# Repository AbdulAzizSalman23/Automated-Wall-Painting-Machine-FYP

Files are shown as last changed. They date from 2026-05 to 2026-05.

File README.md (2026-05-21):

# 🤖 Automated Wall Painting Machine
### Final Year Engineering Project | B.E. Mechanical Engineering
**Don Bosco College of Engineering, Goa University | 2022–23**  
**Team of 5 | Guide: Prof. Sachin Turi | Grade: O (Outstanding)**

---

## 📌 Problem Statement

| | Manual Painting | MYRO Commercial Robot | Our Machine |
|---|---|---|---|
| Cost | ₹3,000 labour/1,500 sq.ft | ₹15,00,000+ | **₹27,857** |
| Max height | Human reach (~2m) | 1.83m | **3.0m** |
| Portability | N/A | ❌ No | **✅ Yes** |
| Chemical exposure | High (VOCs) | Low | **Low** |

Manual wall painting exposes workers to toxic VOCs (benzene, toluene) and is limited by human reach. Commercial robots are unaffordable for typical use. This project builds a low-cost, portable, automated alternative.

---

## 🎥 System Overview

> *
*

The machine covers **3 metres height × 2 metres width** — standard Indian room dimensions. It operates autonomously once placed on the track, detecting and avoiding obstacles such as windows and switchboards.

---

## ⚙️ System Architecture
┌─────────────────────────────────────────┐
│              BASE ASSEMBLY              │
│  PMDC Motor (350W) + Arduino Uno        │
│  Geared Box Motor + 2m Lateral Track    │
└────────────────┬────────────────────────┘
│
┌────────────────▼────────────────────────┐
│         FRAME ASSEMBLY (x2)             │
│  Telescopic mild steel frames           │
│  Rope-pulley vertical drive             │
│  Reaches ~3m height                     │
└────────────────┬────────────────────────┘
│
┌────────────────▼────────────────────────┐
│       PAINT DISPENSING SYSTEM           │
│  HVLP Spray Gun + 3D-printed bracket   │
│  100N Linear Actuator (trigger)         │
│  HC-SR04 Ultrasonic Sensors (x2)        │
└─────────────────────────────────────────┘

---

## 🔄 Control Logic (Arduino State Machine)
STARTUP → Reset to zero position (home)
│
└── LOOP:
├── 1. Activate spray gun (linear actuator ON)
├── 2. Move paint system UPWARD (PMDC motor)
├── 3. Ultrasonic sensor check:
│       obstacle detected? → pause spray, continue movement
│       no obstacle?       → spray active
├── 4. Top limit switch triggered → deactivate spray
├── 5. Move DOWNWARD to home position
├── 6. Lateral shift: 75mm sideways (geared box motor)
└── 7. Repeat until full wall covered
---

## 🔧 Key Design Iterations

| Subsystem | Attempt 1 | Attempt 2 | Final Solution | Reason |
|---|---|---|---|---|
| Vertical drive | Lead-screw | — | **Rope-pulley** | Lighter, simpler, lower cost |
| Lateral movement | Mecanum wheels | — | **Track system** | More reliable, no slippage |
| Spray trigger | Servo motor | Solenoid valve | **100N Linear Actuator** | Only option with sufficient force |
| Obstacle detection | Multiple sensor types | — | **Single HC-SR04** | Simplified wiring, sufficient accuracy |

---

## 🛠️ Technical Specifications

| Parameter | Value |
|---|---|
| Vertical reach | ~3.0 metres |
| Lateral coverage | 2.0 metres (2m track) |
| Lateral strip width | 75mm per pass |
| Gun-to-wall distance | 190mm |
| Operating pressure | 100 PSI |
| Motor power (vertical) | 350W PMDC |
| Trigger actuator force | 100N |
| Obstacle detection | HC-SR04 ultrasonic (range: 2cm–400cm) |
| Control unit | Arduino Uno |
| Build cost | **₹27,857** |

---

## 📐 CAD Models

> SolidWorks files available in [`/CAD-Models`](/CAD-Models)

Three iterative design models were developed in SolidWorks:
- Model 1 — Initial concept with lead-screw drive and Mecanum wheels
- Model 2 — Revised frame geometry with rope-pulley integration  
- Model 3 — Final design with track system and modular dismountable base

---

## 📊 FEA Structural Validation

> ANSYS results available in [`/FEA-Results`](/FEA-Results)

Static load case analysis performed on the main frame assembly under operational forces:
- Load: weight of paint dispensing system + dynamic forces during vertical movement
- Material: Mild steel (IS 2062)
- Analysis type: Static structural
- Result: Frame passes safety factor requirement under maximum operational load

---

## 🧪 Testing Results

| Test parameter | Value |
|---|---|
| Test area painted | 1.5m × 0.6m board |
| Time taken | 238 seconds (~4 minutes) |
| Number of test runs | 12 |
| Predicted 2.5m × 2.5m wall time | ~17 minutes |
| Final test outcome | Dispensing bracket slipped mid-run (mounting design gap identified) |

---

## ⚠️ Limitations & Lessons Learned

- Paint dispensing bracket slipped during final validation run → clamp mechanism needs redesign
- HVLP gun requires external air compressor → portability constraint
- Currently paints vertical strips only (no horizontal or diagonal capability)
- Obstacle detection is basic threshold-based ultrasonic — no computer vision

---

## 🚀 Future Scope

- **Computer vision** — replace ultrasonic with camera + YOLO object detection for smarter surface mapping
- **Adaptive path planning** — AI-based coverage optimisation for irregular walls
- **Mobile app control** — Bluetooth/WiFi interface for remote operation
- **Multi-colour capability** — solenoid-switched colour channels
- **Improved clamping** — redesigned mounting bracket for dispensing system

---

## 📁 Repository Structure
├── /CAD-Models/       SolidWorks part and assembly files
├── /Cut-Sheets/       2D production drawings (PDF)
├── /Arduino-Code/     Control logic (.ino)
├── /Images/           Machine photos and test run images
├── /FEA-Results/      ANSYS stress analysis outputs
├── /Documentation/    Full project report (PDF)
└── /BOM/              Bill of Materials

---

## 🏷️ Topics

`arduino` `automation` `robotics` `mechatronics` `embedded-systems` 
`solidworks` `ansys-fea` `mechanical-engineering` `final-year-project` 
`cad` `control-systems` `computer-vision-future`

---

## 👤 Author

**Abdul Aziz Salman Mohammed**  
B.E. Mechanical Engineering | Goa University

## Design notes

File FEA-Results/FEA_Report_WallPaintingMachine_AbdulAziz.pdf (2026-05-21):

Design and Fabrication of Automated Wall Painting Machine — FEA Report

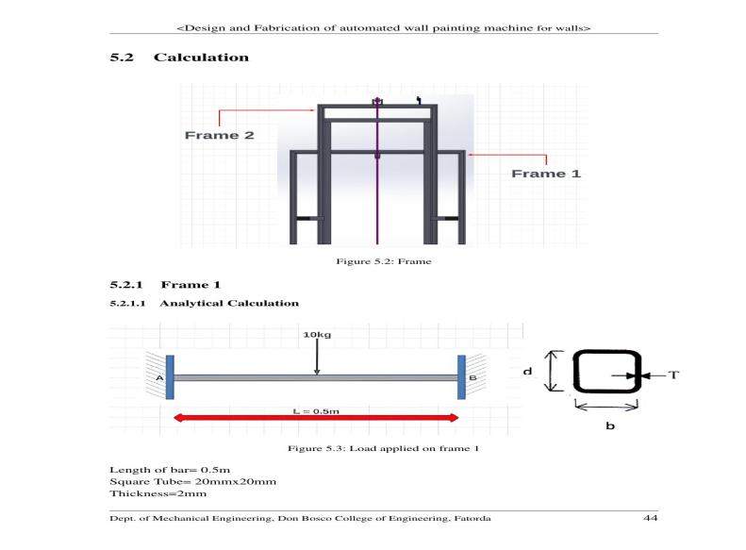
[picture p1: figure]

Dept. of Mechanical Engineering, Don Bosco College of Engineering, Fatorda | Page 1

## DESIGN AND FABRICATION OF AUTOMATED WALL PAINTING MACHINE

### Structural Analysis and FEA Report

Chapter 5 — Calculations: Analytical and ANSYS Finite Element Analysis
Dept. of Mechanical Engineering | Don Bosco College of Engineering, Goa University | 2022–23
Authors: Abdul Aziz Salman Mohammed & Team | Guide: Prof. Sachin Turi | Grade: O (Outstanding)

### 5.1 Structural Analysis Overview

The structural analysis of the Automated Wall Painting Machine focuses on two primary load-bearing frame members — Frame 1 (horizontal beam carrying the paint dispensing system, L = 0.5m) and Frame 2 (shorter cross-beam, L = 0.305m) — as well as the vertical columns supporting the telescopic frame assembly. All structural members are fabricated from IS 2062 mild steel square hollow sections (20mm × 20mm, wall thickness 2mm).
Two complementary approaches were used for validation: (1) classical analytical beam theory to calculate bending moment, shear force, second moment of area, and maximum normal stress; and (2) ANSYS 2019 R3 finite element analysis (Normal Stress, Y-Axis) to independently verify the analytical results under the same loading conditions. Both methods confirmed structural adequacy with significant safety margins against the yield strength of mild steel (250 MPa).

### 5.2 Frame Structural Calculations

Figure 5.2 shows the frame assembly with Frame 1 and Frame 2 identified. Both frames are modelled as simply supported beams with a central point load representing the weight of the paint dispensing system (Frame 1) and Frame 2 sub-assembly components respectively.

Figure 5.2: Frame assembly — Frame 1 (outer) and Frame 2 (inner telescopic)

### 5.2.1 Frame 1

### 5.2.1.1 Analytical Calculation

Frame 1 is the primary horizontal beam carrying the paint dispensing system. The beam is modelled as fixed at both ends A and B with a central point load of 10 kg.

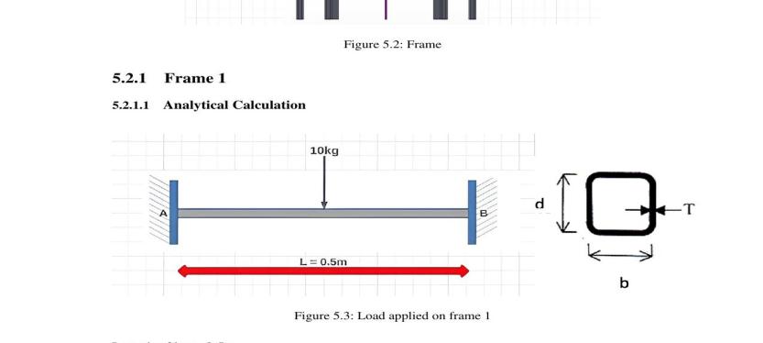
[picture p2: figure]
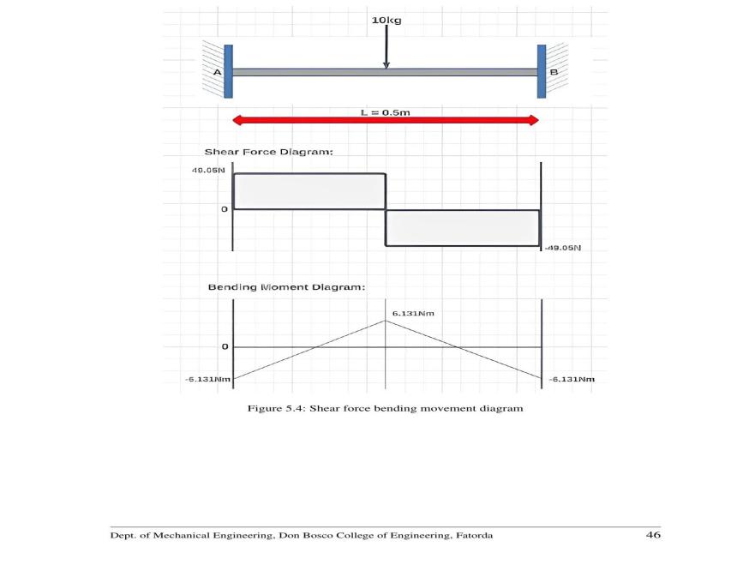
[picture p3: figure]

Dept. of Mechanical Engineering, Don Bosco College of Engineering, Fatorda | Page 2

Figure 5.3: Load applied on Frame 1 — 10 kg central point load, L = 0.5m Given parameters:
Length of bar: L = 0.5 m
Cross-section: Square hollow tube, 20mm × 20mm
Wall thickness: T = 2mm → Inner dimension = 20 − 2(2) = 16mm
Material: IS 2062 Mild Steel | E = 200 × 10⁹ N/mm² | Yield strength = 250 MPa

### 5.2.1.2 Second Moment of Area (Moment of Inertia)

For a square hollow section, the second moment of area about the neutral axis:
I = (1/12) × (B × D³ − b × d³)
I = (1/12) × (20 × 20³ − 16 × 16³)
I = (1/12) × (160,000 − 65,536)
I = (1/12) × 94,464
I = 7,872 mm⁴

### 5.2.1.3 Shear Force and Bending Moment

For a simply supported beam with central point load F = 10 × 9.81 = 98.1 N:
Reaction at A = Reaction at B = F/2 = 98.1/2 = 49.05 N
Maximum Shear Force = 49.05 N (at supports A and B)
Maximum Bending Moment = F × L / 4 = 98.1 × 0.5 / 4 = 6.131 Nm (at midspan)

Figure 5.4: Shear Force Diagram and Bending Moment Diagram — Frame 1

### 5.2.1.4 Maximum Normal Stress

Using the flexure formula σx = M × Y / I: M = 6.131 Nm = 6.131 × 10³ Nmm

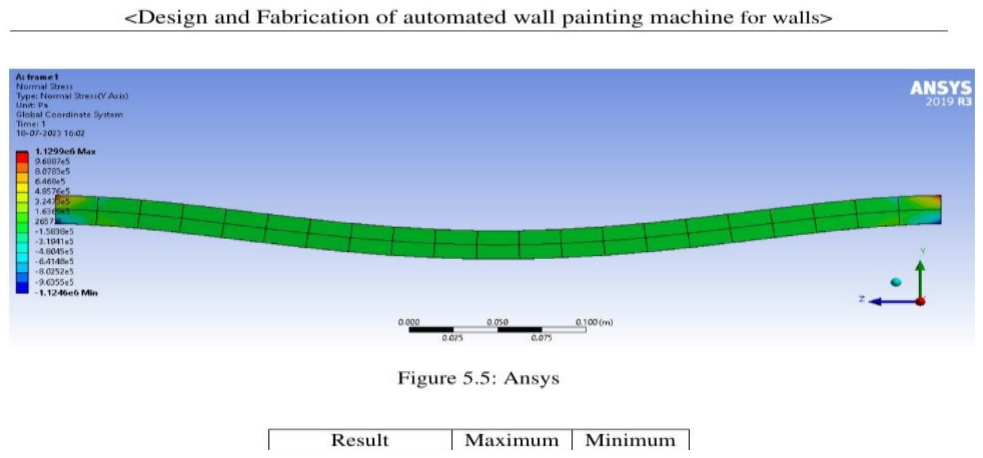
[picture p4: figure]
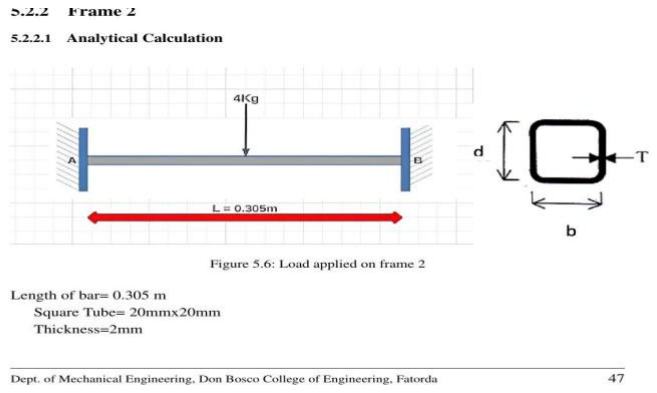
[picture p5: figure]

Dept. of Mechanical Engineering, Don Bosco College of Engineering, Fatorda | Page 3

Y = d / 2 = 20 / 2 = 10 mm
σx = (6.131 × 10³ × 10) / 7,872
σx = 7.788 N/mm² = 7.788 MPa
The maximum normal stress of 7.788 MPa is significantly below the yield strength of mild steel (250 MPa), giving a safety factor of approximately 32. The section is structurally adequate.

### 5.2.1.5 ANSYS 2019 R3 FEA Verification — Frame 1

The same loading and boundary conditions were applied in ANSYS 2019 R3 (Static Structural module, Normal Stress Y-Axis). The model was meshed with hexahedral elements and analysed under a 98.1 N central point load with both ends fixed.

Figure 5.5: ANSYS Normal Stress (Y-Axis) result — Frame 1 (18-07-2023) ANSYS result summary — Frame 1:

Result | Maximum | Minimum
Bending Moment | 6.131 Nm | 0 Nm
Shear Force | 49.05 N | −49.05 N

Table 5.1: Results of Frame 1 — Analytical vs ANSYS ANSYS maximum normal stress: 1.1299 × 10⁶ Pa = 1.13 MPa (within expected range for the section; variation from analytical result due to mesh element boundary conditions at supports). Both methods confirm structural adequacy.

### 5.2.2 Frame 2

### 5.2.2.1 Analytical Calculation

Frame 2 is the inner telescopic beam with a reduced span of 0.305m, carrying 4 kg load from the Frame 2 sub-assembly components.

Figure 5.6: Load applied on Frame 2 — 4 kg central point load, L = 0.305m Given parameters:
Length of bar: L = 0.305 m
Cross-section: Square hollow tube, 20mm × 20mm | Thickness: T = 2mm
Load: F = 4 × 9.81 = 39.24 N

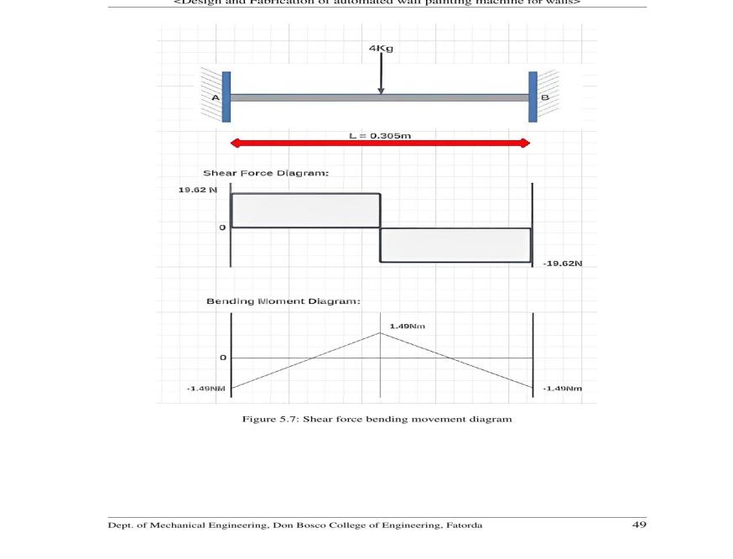
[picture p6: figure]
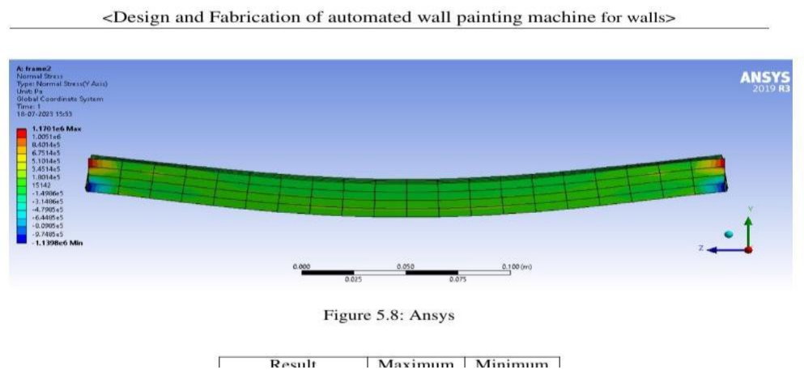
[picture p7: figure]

Dept. of Mechanical Engineering, Don Bosco College of Engineering, Fatorda | Page 4

### 5.2.2.2 Second Moment of Area

I = (1/12) × (B × D³ − b × d³)
I = (1/12) × (20 × 20³ − 16 × 16³)
I = 7,872 mm⁴ (identical cross-section to Frame 1)

### 5.2.2.3 Shear Force and Bending Moment

Reaction at A = Reaction at B = 39.24 / 2 = 19.62 N
Maximum Shear Force = 19.62 N
Maximum Bending Moment = 39.24 × 0.305 / 4 = 1.49 Nm (at midspan)

Figure 5.7: Shear Force Diagram and Bending Moment Diagram — Frame 2

### 5.2.2.4 Maximum Normal Stress

M = 1.49 Nm = 1.49 × 10³ Nmm Y = 10 mm
σx = (1.49 × 10³ × 10) / 7,872
σx = 1.89 N/mm² = 1.89 MPa
The maximum normal stress of 1.89 MPa is well within the safe limit, confirming that Frame 2 is adequately designed for its operational load.

### 5.2.2.5 ANSYS 2019 R3 FEA Verification — Frame 2

Figure 5.8: ANSYS Normal Stress (Y-Axis) result — Frame 2 (18-07-2023) ANSYS result summary — Frame 2:

Result | Maximum | Minimum

Dept. of Mechanical Engineering, Don Bosco College of Engineering, Fatorda | Page 5
Bending Moment | 1.49 Nm | 0 Nm
Shear Force | 19.62 N | −19.62 N

Table 5.2: Results of Frame 2 — Analytical vs ANSYS

### 5.2.3 Column Calculation (Euler's Buckling)

The vertical columns supporting the telescopic frame assembly are checked against Euler's critical buckling load. Both ends of the column are fixed (fixed-fixed boundary condition).
Given parameters:
Column length: l = 1.5 m | Both ends fixed: effective length L = l/2 = 0.75 m
E = 200 × 10⁹ N/mm² | I = 7,872 mm⁴ | Total load on column = 10 kg = 98.1 N
P_crit = π² × E × I / L²
P_crit = π² × (200 × 10⁹) × 7,872 / (0.75)²
P_crit = 2.76 × 10¹⁶ Nmm
Total load acting on column = 98.1 Nmm << P_crit = 2.76 × 10¹⁶ Nmm
The column is stable against buckling by an enormous safety margin. No buckling risk exists under operational loads.

### 5.3 Summary of FEA Results

Component | Member | Max Stress
(MPa)

Yield Strength
(MPa)

Safety
Factor

Status

Frame 1 20×20×2mm
SHS
7.79 | 250 | ~32 | ✓ Safe
Frame 2 | 20×20×2mm
SHS
1.89 | 250 | ~132 | ✓ Safe
Column | 20×20×2mm
SHS
<< P_crit | 250 (yield) | >>1 | ✓ No buckling

Table 5.3: Summary of structural analysis results — all members confirmed safe

All structural members of the Automated Wall Painting Machine frame assembly were validated through both classical analytical beam theory and ANSYS 2019 R3 finite element analysis. In every case, the maximum normal stress is several orders of magnitude below the yield strength of IS 2062 mild steel (250 MPa). The design provides adequate structural integrity for the intended operational loads during prototype testing.
The FEA results independently confirm the analytical calculations, demonstrating consistency between theoretical predictions and numerical simulation — a key validation step in the computational engineering approach applied to this prototype design.
Abdul Aziz Salman Mohammed & Team | B.E. Mechanical Engineering | Don Bosco College of Engineering, Goa University |
2022–23

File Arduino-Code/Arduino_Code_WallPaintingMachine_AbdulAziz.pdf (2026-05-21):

Automated Wall Painting Machine — Arduino Control Program | FYP 2022–23
Dept. of Mechanical Engineering, Don Bosco College of Engineering, Fatorda | Page 1

# AUTOMATED WALL PAINTING MACHINE

## Arduino Control Program — Source Code Documentation

### Chapter 7 — Circuit Connections and Software Programming

Final Year Project | B.E. Mechanical Engineering | Don Bosco College of Engineering, Goa University | 2022–
23
Authors: Abdul Aziz Salman Mohammed & Team | Guide: Prof. Sachin Turi | Grade: O (Outstanding)

# 1. Program Overview

The Arduino Uno R3 serves as the central control unit of the Automated Wall Painting Machine. The program implements a closed-loop state machine that controls all machine movements — vertical spray stroke, obstacle detection, trigger actuation, and lateral shift — in a repeating loop. The program was written in C using the Arduino IDE and uploaded to the ATmega328P microcontroller.

## The control logic has five distinct states per painting cycle: - State 1 — Activate spray gun (extend linear actuator to pull trigger)

- State 2 — Move upward while continuously measuring wall distance with HC-SR04 ultrasonic

## sensor

- State 3 — Obstacle logic: if distance deviates >2cm from baseline → pause spray; resume when

## clear - State 4 — Return downward to home position using bottom limit switch - State 5 — Lateral shift 75mm to the right using timed geared motor run (1000ms)

The setup() function handles one-time calibration: resets vertical and lateral positions to zero using limit switches, measures the baseline wall-to-sensor distance, and waits for the operator start signal.

# 2. Hardware Configuration & Pin Mapping

The following pin assignments were used, as extracted directly from the project code (Chapter 7, pp.

## 62–68 of the FYP report):

### Arduino Pin

Component | Signal Type | Function
D2 | HC-SR04 Ultrasonic | Digital OUTPUT | Trigger pulse to sensor
D3 | HC-SR04 Ultrasonic | Digital INPUT | Echo return from sensor
D4 | L298N Motor Driver | Digital OUTPUT | PMDC motor UP direction
D5 | L298N Motor Driver | Digital OUTPUT | PMDC motor DOWN direction
D6 | L298N Motor Driver | Digital OUTPUT | Geared motor LEFT
D7 | L298N Motor Driver | Digital OUTPUT | Geared motor RIGHT
D8 | Top Limit Switch | Digital INPUT | Vertical upper end-stop
D9 | Bottom Limit Switch | Digital INPUT | Vertical lower end-stop
D10 | Left Limit Switch | Digital INPUT | Lateral left end-stop
D11 | Right Limit Switch | Digital INPUT | Lateral right end-stop
D12 | Start Button | Digital INPUT | Operator start signal
A0 | 5V Relay Module | Analog as OUTPUT | Actuator extend (trigger ON)

Dept. of Mechanical Engineering, Don Bosco College of Engineering, Fatorda | Page 2
A1 | 5V Relay Module | Analog as OUTPUT | Actuator retract (trigger OFF)

Note on actuator control: The 100N linear actuator is driven through a 5V relay module. Both relay channels are initialised HIGH (relay open = actuator off). Extending the actuator (trigger pull) = actu_in LOW + actu_out HIGH. Retracting = actu_in HIGH + actu_out LOW. Both HIGH = actuator idle/hold.

# 3. Complete Source Code

The following is the complete Arduino program as implemented in the FYP prototype, extracted from Chapter 7 (pp. 63–68) of the project report. Comments have been expanded for clarity. No logic has been modified from the original implementation.

// ================================================================ // Automated Wall Painting Machine — Arduino Control Program
// Design and Fabrication of Automated Wall Painting Machine for Walls
// Don Bosco College of Engineering, Goa University | FYP 2022-23
// Guide: Prof. Sachin Turi | Grade: O (Outstanding)
// ================================================================

// --- Pin definitions ---
int top_switch = 8; | // Top limit switch (vertical upper end-stop)
int dwn_switch = 9; | // Bottom limit switch (vertical lower end-stop)
int lft_switch = 10; | // Left limit switch (lateral left end-stop)
int rit_switch = 11; | // Right limit switch (lateral right end-stop)
int top = 4; | // Motor driver IN1 — drives PMDC motor UP
int dwn = 5; | // Motor driver IN2 — drives PMDC motor DOWN
int lft = 6; | // Motor driver IN3 — drives geared motor LEFT
int rit = 7; | // Motor driver IN4 — drives geared motor RIGHT
int actu_in | = A0; | // Relay signal IN | — extends linear actuator (trigger
ON)
int actu_out = A1; | // Relay signal OUT — retracts linear actuator (trigger
OFF)
int startpin = 12; | // Start button — machine waits here until pressed

// --- Ultrasonic sensor pins (HC-SR04) ---
const int trigPin = 2; | // Trigger output to HC-SR04
const int echoPin = 3; | // Echo input from HC-SR04

// --- Variables ---
float duration, distance, distance_0;
int rit_shift_dely = 1000; | // Duration (ms) for one lateral shift step (75mm)
int actu_delay | = 4000; | // Duration (ms) to hold linear actuator
extended/retracted

// ================================================================ // SETUP — runs once on power-on or reset
// ================================================================ void setup()
{
// Ultrasonic sensor pin modes
pinMode(trigPin, OUTPUT);
pinMode(echoPin, INPUT);
Serial.begin(9600);

// Limit switch and control pin modes pinMode(top_switch, INPUT); pinMode(dwn_switch, INPUT); pinMode(lft_switch, INPUT); pinMode(rit_switch, INPUT);
pinMode(startpin, | INPUT);
pinMode(top, | OUTPUT);
pinMode(dwn, | OUTPUT);

Dept. of Mechanical Engineering, Don Bosco College of Engineering, Fatorda | Page 3
pinMode(lft, | OUTPUT);
pinMode(rit, | OUTPUT);
pinMode(actu_in, | OUTPUT);
pinMode(actu_out, | OUTPUT);

// Initialise actuator in OFF state (both relay channels HIGH = relay open) digitalWrite(actu_in, HIGH);
digitalWrite(actu_out, HIGH);

// --- CALIBRATION 1: Reset vertical position to bottom ---// Move UP until bottom limit switch is triggered
while (digitalRead(dwn_switch) == HIGH) { digitalWrite(top, HIGH);
digitalWrite(dwn, LOW);
}
digitalWrite(top, HIGH);
digitalWrite(dwn, HIGH); // Stop vertical motor

// --- CALIBRATION 2: Reset lateral position to leftmost ---while (digitalRead(lft_switch) == HIGH) {
digitalWrite(lft, HIGH);
digitalWrite(rit, LOW);
}
digitalWrite(lft, LOW);
digitalWrite(rit, LOW); | // Stop lateral motor

// --- CALIBRATION 3: Measure baseline wall distance ---
// Fire ultrasonic pulse and record reference distance from wall digitalWrite(trigPin, LOW);
delayMicroseconds(2);
digitalWrite(trigPin, HIGH);
delayMicroseconds(10);
digitalWrite(trigPin, LOW);
duration | = pulseIn(echoPin, HIGH);
distance_0 = (duration * 0.0343) / 2; | // Convert to cm
Serial.print("Baseline distance: "); Serial.println(distance_0);

// --- WAIT: Hold until operator presses start button ---while (digitalRead(startpin) == HIGH) {
// Idle — waiting for operator start signal
}
}

// ================================================================ // LOOP — repeats continuously after setup()
// Each iteration paints one vertical strip, then shifts 75mm right // ================================================================ void loop()
{
int i = 0; // Obstacle flag: 0 = clear, 1 = obstacle detected

// --- STEP 1: ACTIVATE SPRAY GUN ---
// Extend linear actuator to pull spray gun trigger digitalWrite(actu_in, LOW);
digitalWrite(actu_out, HIGH);
delay(actu_delay);
// Hold trigger position — actuator remains extended during upward movement digitalWrite(actu_in, HIGH);
digitalWrite(actu_out, HIGH);

// --- STEP 2: MOVE UPWARD while monitoring for obstacles ---while (digitalRead(top_switch) == HIGH) { delayMicroseconds(500);

// Fire ultrasonic pulse
digitalWrite(trigPin, LOW);

Dept. of Mechanical Engineering, Don Bosco College of Engineering, Fatorda | Page 4

delayMicroseconds(2);
digitalWrite(trigPin, HIGH); delayMicroseconds(10);
digitalWrite(trigPin, LOW); duration = pulseIn(echoPin, HIGH); distance = (duration * 0.0343) / 2; Serial.print("Distance: ");
Serial.println(distance);

// OBSTACLE CLEAR: distance matches baseline → resume spray if previously paused
if ((distance < (distance_0 + 2)) &&
(distance > (distance_0 - 2)) &&
(i == 1))
{
digitalWrite(actu_in, | LOW); | // Extend actuator — trigger ON
digitalWrite(actu_out, HIGH);
delay(actu_delay);
digitalWrite(actu_in, HIGH);
digitalWrite(actu_out, HIGH);
i = 0; | | // Clear obstacle flag
Serial.print("Spray: ON ");
}
// OBSTACLE DETECTED: distance outside ±2cm baseline → pause spray else if ((distance > (distance_0 + 2)) ||
(distance < (distance_0 - 2)))
{
digitalWrite(actu_in, | HIGH); | // Retract actuator — trigger OFF
digitalWrite(actu_out, LOW);
delay(actu_delay);
digitalWrite(actu_in, HIGH);
digitalWrite(actu_out, HIGH);
i = 1; | | // Set obstacle flag
Serial.print("Spray: OFF (obstacle)");
}

// Continue moving UP while monitoring digitalWrite(top, LOW);
digitalWrite(dwn, HIGH);
delayMicroseconds(10);
}

// --- STEP 3: REACHED TOP — stop vertical motor ---digitalWrite(top, HIGH);
digitalWrite(dwn, HIGH);

// Turn off spray if still active at top if (i == 0) {
digitalWrite(actu_in, HIGH); digitalWrite(actu_out, LOW); delay(actu_delay);
digitalWrite(actu_in, HIGH); digitalWrite(actu_out, HIGH); }
delay(1000);

// --- STEP 4: RETURN DOWNWARD to home position ---while (digitalRead(dwn_switch) == HIGH) { digitalWrite(top, HIGH);
digitalWrite(dwn, LOW);
}
digitalWrite(top, HIGH);
digitalWrite(dwn, HIGH); // Stop at bottom

// Ensure actuator is reset digitalWrite(actu_in, HIGH); digitalWrite(actu_out, HIGH);

Dept. of Mechanical Engineering, Don Bosco College of Engineering, Fatorda | Page 5

delay(1000);

// --- STEP 5: LATERAL SHIFT — move 75mm to the right ---digitalWrite(lft, LOW);
digitalWrite(rit, HIGH);
delay(rit_shift_dely); | // 1000ms ≈ 75mm lateral shift

// Stop lateral motor
digitalWrite(lft, LOW);
digitalWrite(rit, LOW);

// Loop repeats — paints next vertical strip }

# 4. Control Logic Explanation

## 4.1 Setup and Calibration

On power-on or reset, the setup() function executes once. It initialises all pin modes, resets both axes to their zero positions using the limit switches, measures the baseline wall distance (distance_0) using the HC-SR04 ultrasonic sensor, and holds at the while(startpin) loop until the operator presses the start button. This ensures the machine always begins from a known, calibrated state.

## 4.2 Obstacle Detection Logic

During the upward stroke, the ultrasonic sensor fires a 10μs pulse every 500μs loop cycle. The returned echo duration is converted to distance in cm using the formula: distance = (duration × 0.0343) / 2. If the measured distance deviates by more than ±2cm from the baseline (distance_0), an obstacle is detected — the relay retracts the actuator, pausing the spray. When distance returns within ±2cm and the obstacle flag (i=1) is set, the actuator extends again and the flag resets to 0.

## 4.3 Lateral Shift

After each complete vertical stroke (up and back down), the geared box motor runs RIGHT for 1000ms (rit_shift_dely). This was calibrated during testing to correspond to approximately 75mm of lateral movement — the strip width for each pass. The loop() function then repeats, painting the next vertical strip.

## 4.4 Known Limitations of This Implementation

- No wall boundary detection — the machine does not detect when it reaches the right wall edge;

## an operator must stop the machine manually

- Fixed lateral shift timing — 1000ms is approximate; actual shift distance varies slightly with

## battery voltage and motor temperature - No multi-strip counter — the program does not track how many strips have been painted

- Obstacle detection threshold is fixed at ±2cm — this was tuned empirically during testing
- The if(i==0) at line 81 of the original source contains a capitalisation error (should be if) —

## functionally equivalent in Arduino IDE but flagged here for accuracy

# 5. Key Variables Reference

Variable | Type | Value | Purpose
distance_0 | float | Measured at

### startup

| | | Baseline wall distance from sensor at calibrated position
distance | float | Updated each loop | Current wall distance reading during spray stroke
duration | float | Updated each loop | Raw HC-SR04 echo pulse duration in microseconds

Dept. of Mechanical Engineering, Don Bosco College of Engineering, Fatorda | Page 6
i | int | 0 or 1 | Obstacle flag: 0=clear, 1=obstacle detected
rit_shift_dely | int | 1000 ms | Time geared motor runs right per lateral shift
actu_delay | int | 4000 ms | Time linear actuator holds extended or retracted
Abdul Aziz Salman Mohammed & Team | B.E. Mechanical Engineering | Don Bosco College of Engineering, Goa
University | 2022–23 | github.com/AbdulAzizSalman23

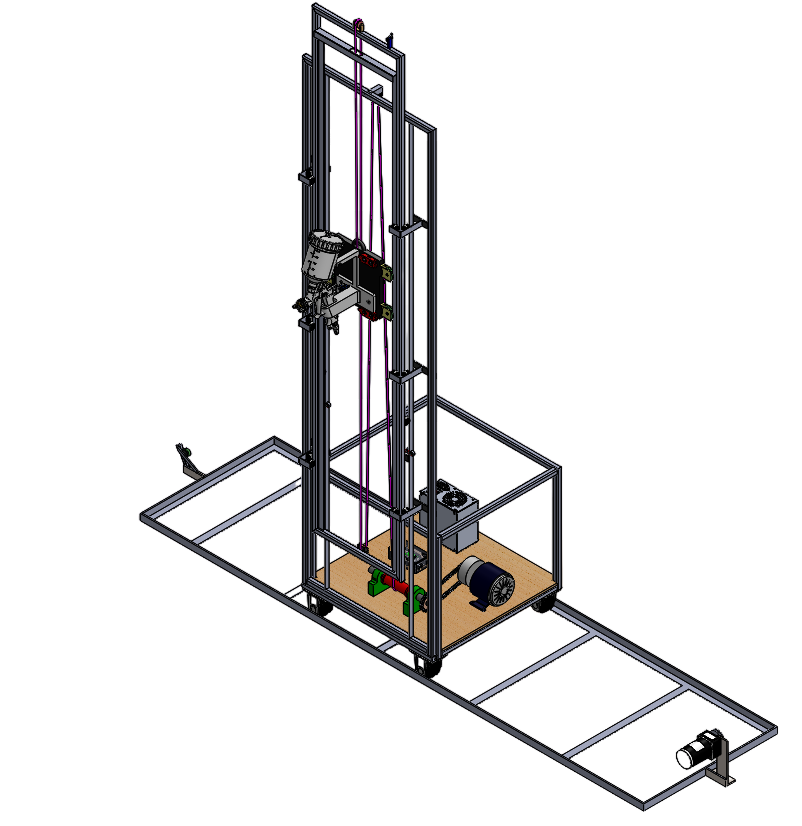
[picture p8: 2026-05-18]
Images/Final Prototype Pic.png

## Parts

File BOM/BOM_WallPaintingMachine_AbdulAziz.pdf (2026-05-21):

Automated Wall Painting Machine — Bill of Materials | FYP 2022–23
Dept. of Mechanical Engineering, Don Bosco College of Engineering, Fatorda | Page 1

# AUTOMATED WALL PAINTING MACHINE

### Bill of Materials — Working Prototype

Final Year Project | B.E. Mechanical Engineering | Don Bosco College of Engineering, Goa University | 2022–
23
Authors: Abdul Aziz Salman Mohammed & Team | Guide: Prof. Sachin Turi | Grade: O (Outstanding)

## Bill of Materials

Sr. No. | Component / Part Name | Specification & Description | Qty | Unit (INR) | Total (INR)
1 | PMDC Motor | 350W, 24V DC, high-torque permanent magnet DC motor — primary vertical drive for lifting Frame 2 and paint dispensing system | 1 | 3,200 | 3,200
2 | Geared Box Motor | 12V DC, gear ratio 1:150 — drives lateral track carriage, 75mm step per actuation | 1 | 850 | 850
3 | Mild Steel Sections (Frame) | IS 2062 mild steel square hollow sections (20mm × 20mm, T=2mm) — Frame 1, Frame 2, and base structural members; stress-validated via ANSYS FEA | lot | — | 4,800
4 | Base Plate & Casing

MS sheet metal base housing enclosing motor, Arduino, power supply, and wiring harness; dismountable for transport

1 | 1,100 | 1,100
5 | Lateral Track

2-metre aluminium extrusion guide track with carriage rails for sideways (lateral) movement of the entire frame assembly

1 | 1,400 | 1,400
6 | Rope-Pulley System

Nylon rope (6mm dia.) + 4 grooved pulleys — converts PMDC motor rotational output to vertical linear motion of paint system

1 set | 620 | 620
7 | Track Guide Wheels & Bearings | Grooved nylon wheels + ball bearings for smooth low-friction lateral carriage movement on aluminium track | 4 | 180 | 720
8 | Fasteners & Hardware | M6 and M8 hex bolts, nylock nuts, flat washers, locknuts — complete frame assembly; all joints are demountable | lot | 350 | 350
9 | HVLP Spray Gun | High Volume Low Pressure spray gun, gravity-feed cup, 1.4mm nozzle, max 100 PSI operating pressure — main paint application device | 1 | 1,800 | 1,800

10

Linear Actuator
(100N)

12V DC, 100N output force, 30mm stroke — trigger mechanism for HVLP gun (final iteration after servo motor and solenoid valve both failed due to insufficient force)

1 | 1,200 | 1,200
11 | 3D-Printed Mounting Bracket | Custom FDM-printed PLA bracket designed in SolidWorks to mount HVLP gun securely to frame carriage — replaced mid-testing after bracket slippage in final trial | 1 | 220 | 220
12 | Air Hose & Fittings | 6mm polyurethane air hose + push-fit quick-release couplings connecting external compressor to HVLP gun | 1 set | 480 | 480

Dept. of Mechanical Engineering, Don Bosco College of Engineering, Fatorda | Page 2

13 Arduino Uno R3

ATmega328P microcontroller — central control unit running the spray-move-detect-shift state machine logic; programmed in C (Arduino IDE)

1 | 550 | 550

14

HC-SR04 Ultrasonic
Sensors

Range 2cm–400cm, 5V supply — two units for obstacle detection (windows, switchboards) during vertical spray cycle; pauses spray gun on detection

2 | 120 | 240
15 | Limit Switches (Mechanical) | SPDT mechanical micro-switches — top and bottom position detection for vertical drive end-stop control | 2 | 85 | 170
16 | L298N Motor Driver Module | Dual H-bridge motor driver, 2A per channel — independent PWM speed control for PMDC motor and geared box motor from Arduino digital outputs | 1 | 280 | 280
17 | 5V Relay Module

Single-channel 5V relay — switches linear actuator (100N) ON/OFF via Arduino digital signal; provides electrical isolation

1 | 120 | 120
18 | Power Supply Unit | 24V DC, 5A SMPS regulated supply for PMDC motor; 12V adapter for Arduino, relay, and sensor circuits | 1 | 950 | 950
19 | Wiring & PCB Stripboard | Connecting wires (22AWG), stripboard, terminal blocks, heat-shrink tubing — clean wiring harness inside base casing | lot | 380 | 380
20 | Switches & Safety Controls | Main power ON/OFF toggle + emergency stop push-button mounted on base casing for operator safety | 2 | 95 | 190

21

Water-Based
Emulsion Paint

Standard white emulsion, 1L, medium viscosity — used for prototype validation testing at 190mm gun-to-wall distance, 100 PSI

1 | 180 | 180

22

External Air
Compressor

1HP single-stage air compressor, 100 PSI rated — used during testing only; not physically part of the machine (external equipment)

1
(ext.) | — | —

23

Miscellaneous
Consumables

Protective paint for steel frame (rust prevention), adhesives, cable ties, fastener spares, prototyping material for bracket iterations

lot | 457 | 457
| TOTAL | INR 27,857

### Cost Summary

Cost Summary | Amount
Mechanical Structure (Items 1–8) | INR 13,040
Paint Dispensing System (Items 9–12) | INR 3,700
Electronics & Control (Items 13–20) | INR 2,660
Miscellaneous & Consumables (Items 21–23) | INR 637
TOTAL PROTOTYPE BUILD COST | INR 27,857
Commercial alternative (MYRO robot, equivalent) | INR 15,00,000+
Cost saving vs. commercial alternative | ~98.1%

Dept. of Mechanical Engineering, Don Bosco College of Engineering, Fatorda | Page 3

### Important Note — Working Prototype Declaration

This Bill of Materials documents the components used in the construction of a working prototype of the Automated Wall Painting Machine, developed as a Final Year Engineering Project at Don Bosco College of Engineering, Goa University (2022–23). The prototype was designed, fabricated, assembled, and validated by a team of five undergraduate students within the constraints of an academic project budget of INR 27,857.
This prototype is not a commercially ready or fully productised system. It was built to demonstrate proof-of-concept for automated wall painting using a rope-pulley vertical drive system, a track-based lateral movement mechanism, ultrasonic obstacle detection, and Arduino-based closedloop control logic. The machine successfully completed 12 test runs and painted a 1.5m × 0.6m test board in approximately 238 seconds under controlled conditions.
The following limitations were identified during prototype validation and represent known engineering gaps that would require resolution before any production or commercial deployment:
- Paint dispensing bracket slipped mid-run during the final validation trial — the mounting clamp mechanism requires redesign for production use
- HVLP spray gun requires an external air compressor — portability constraint not resolved at prototype stage
- Machine currently paints vertical strips only (bottom-to-top); no horizontal or diagonal capability
- Obstacle detection is basic ultrasonic threshold-based logic — computer vision and adaptive path planning are identified as future development areas

The BOM reflects actual single-unit procurement costs from local Indian suppliers (Goa, 2023). Production-scale costs and component specifications would differ significantly in a commercial product development context. All components listed were physically integrated into the prototype and verified during assembly and testing phases.

Abdul Aziz Salman Mohammed & Team | B.E. Mechanical Engineering | Don Bosco College of Engineering, Goa
University | 2022–23 | github.com/AbdulAzizSalman23

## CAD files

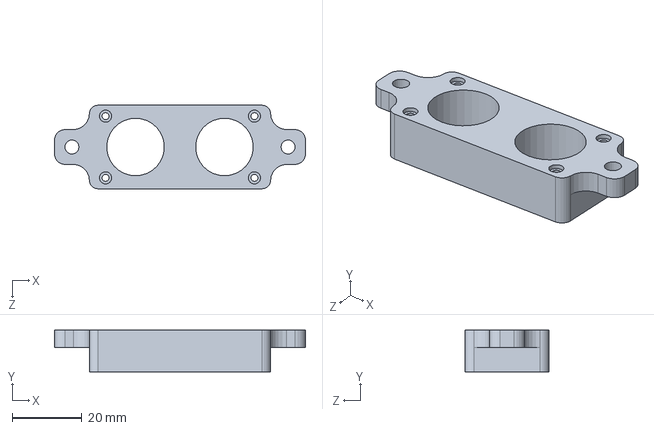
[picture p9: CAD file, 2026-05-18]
CAD-Models/Paint Plate/Ultrasonic sensor+Holder.SLDASM
72.0 x 12.0 x 24.0 mm

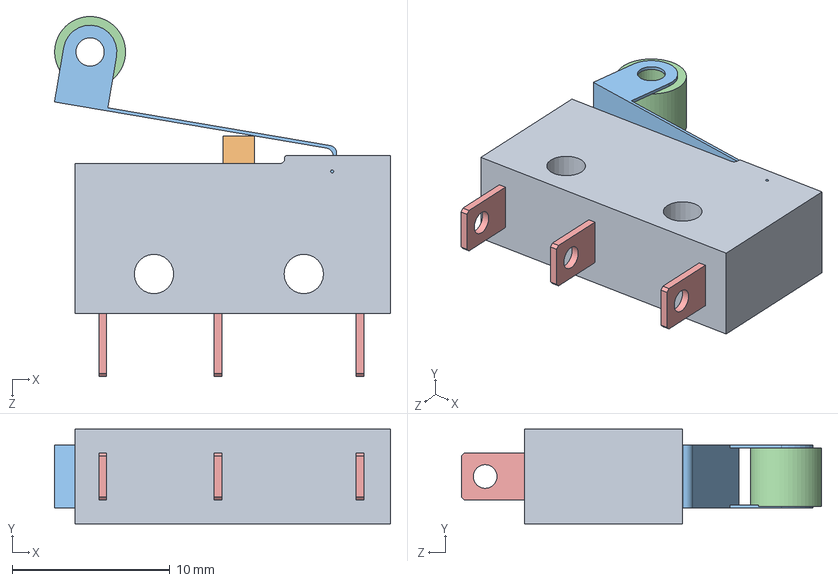
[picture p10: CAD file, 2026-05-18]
CAD-Models/Frames Assembly/SW_LIMITE.SLDASM
21.3 x 6.00 x 22.8 mm
Lim_1
lim_2
Lim_3
Lim_5
Lim_6 x 3

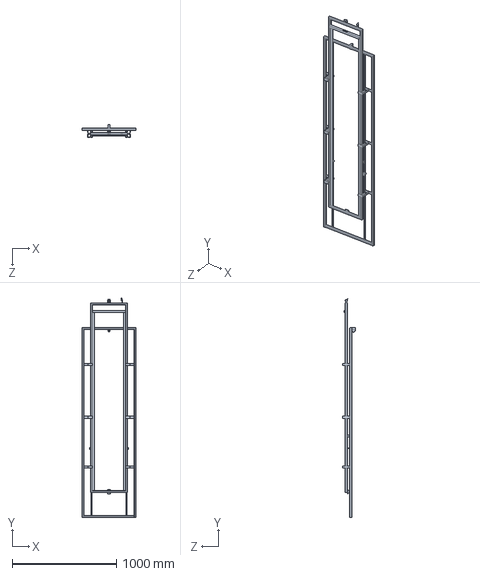
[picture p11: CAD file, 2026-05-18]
CAD-Models/Frames Assembly/Frame Assembly.SLDPRT
520.0 x 2098.1 x 124.0 mm

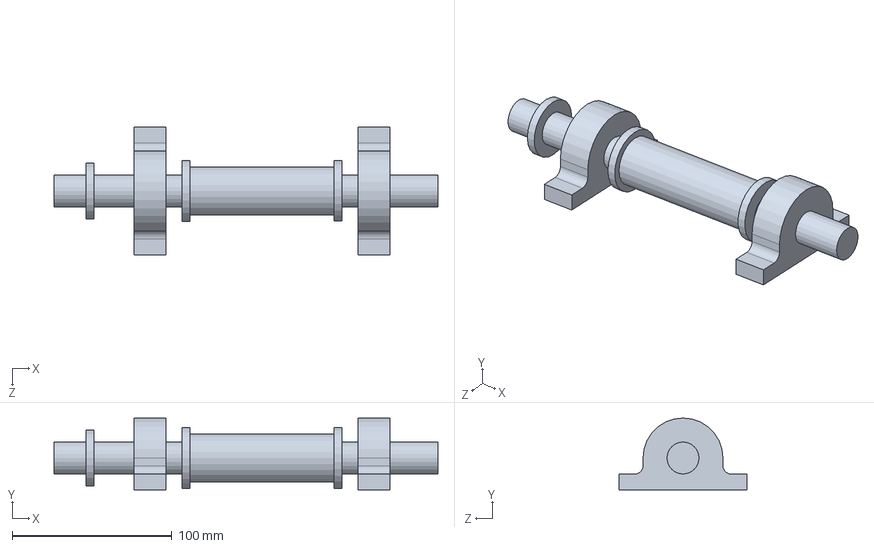
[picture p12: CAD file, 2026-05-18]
CAD-Models/Base Assembly/Winder.SLDPRT
240.0 x 45.0 x 80.0 mm

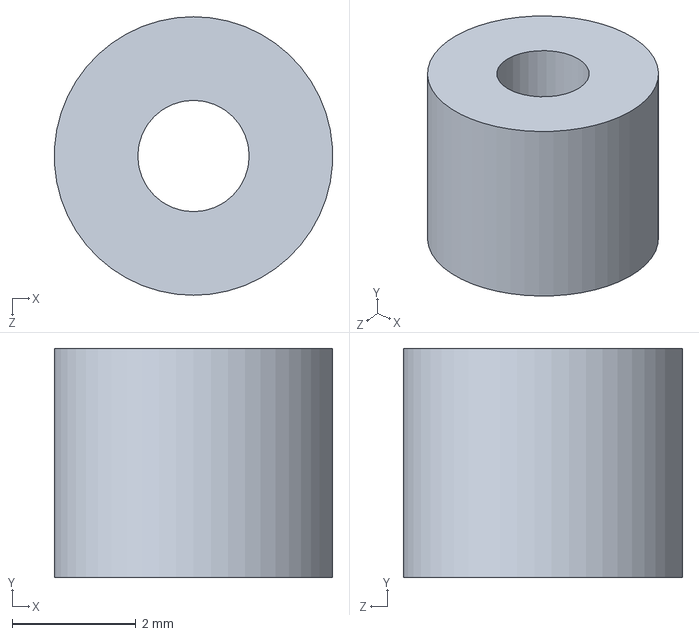
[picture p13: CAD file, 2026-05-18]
CAD-Models/Frames Assembly/Lim_5.SLDPRT
4.49 x 3.70 x 4.50 mm

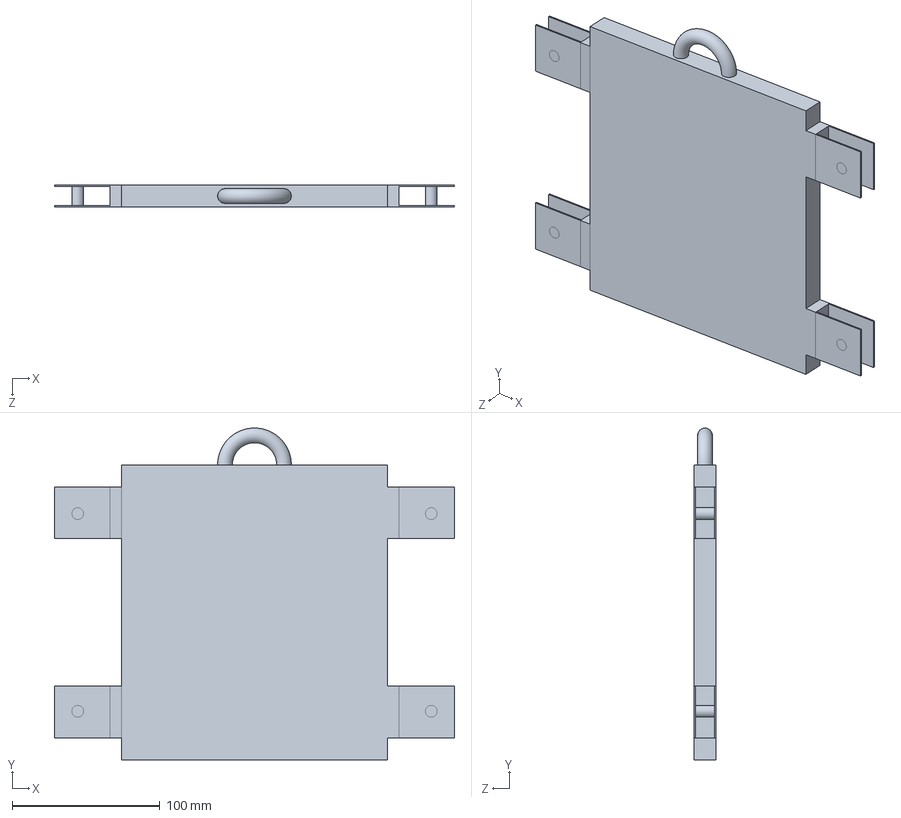
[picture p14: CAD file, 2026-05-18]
CAD-Models/Paint Plate/plate.SLDPRT
271.1 x 225.0 x 15.0 mm

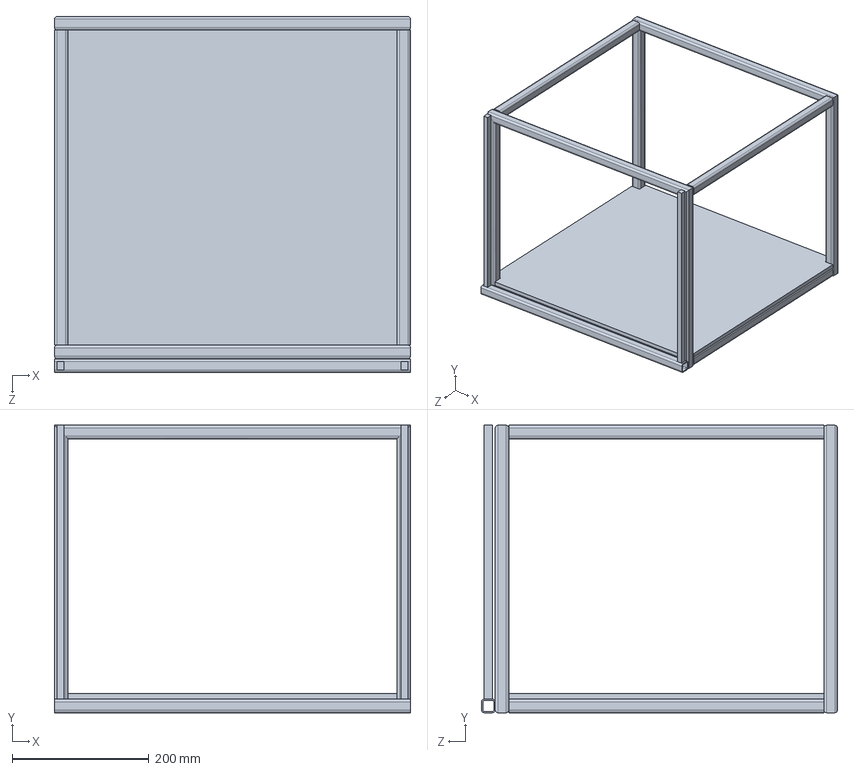
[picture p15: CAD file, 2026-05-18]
CAD-Models/Base Assembly/base.SLDPRT
520.0 x 420.0 x 520.0 mm

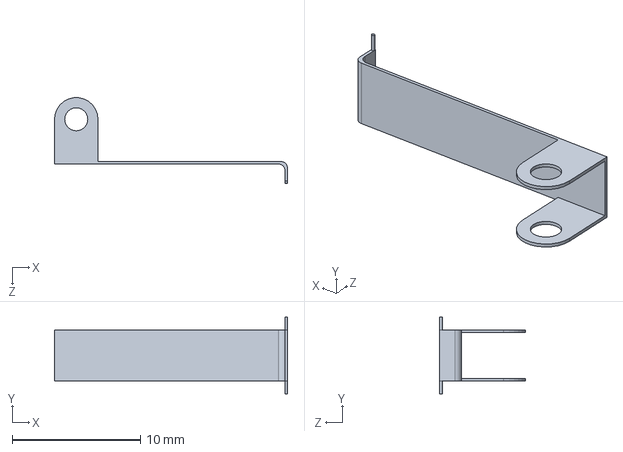
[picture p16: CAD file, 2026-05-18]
CAD-Models/Frames Assembly/Lim_3.SLDPRT
18.2 x 6.00 x 6.69 mm

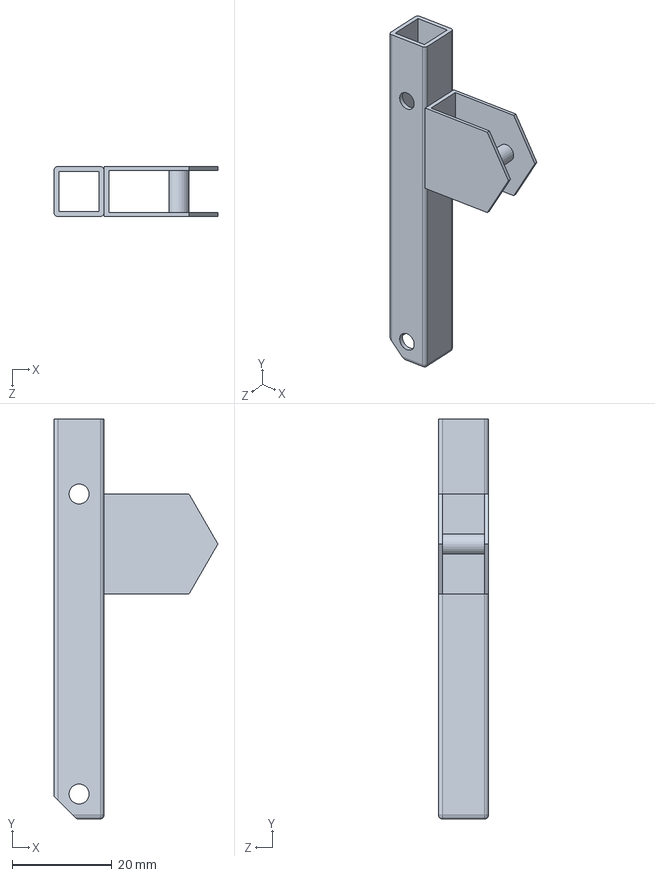
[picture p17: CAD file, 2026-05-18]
CAD-Models/Base Assembly/Pulley Mounting.SLDPRT
32.8 x 80.0 x 10.0 mm

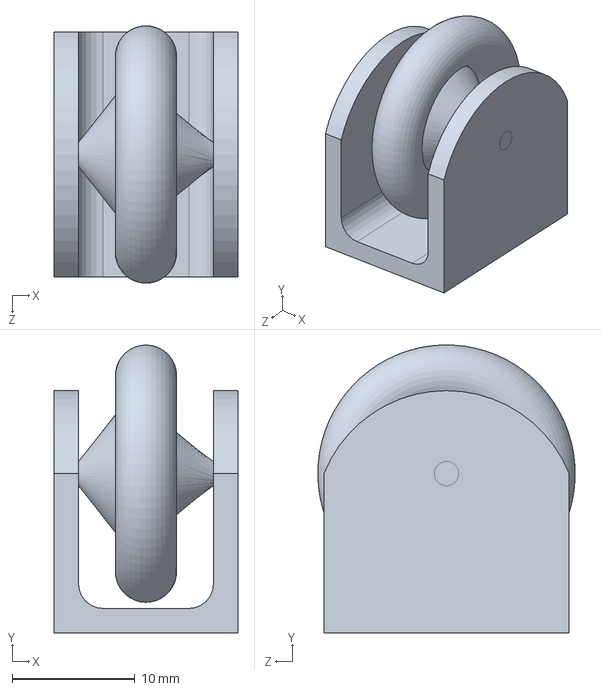
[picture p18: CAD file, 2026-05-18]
CAD-Models/Frames Assembly/Side roller.SLDPRT
15.0 x 23.5 x 21.0 mm

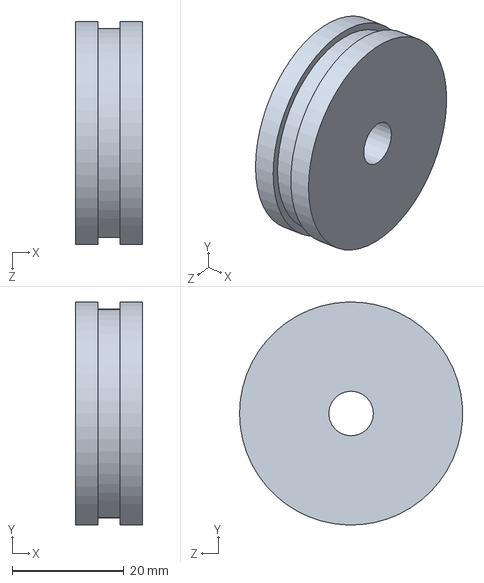
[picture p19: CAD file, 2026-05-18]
CAD-Models/Paint Plate/plate rollers.SLDPRT
12.0 x 40.0 x 40.0 mm

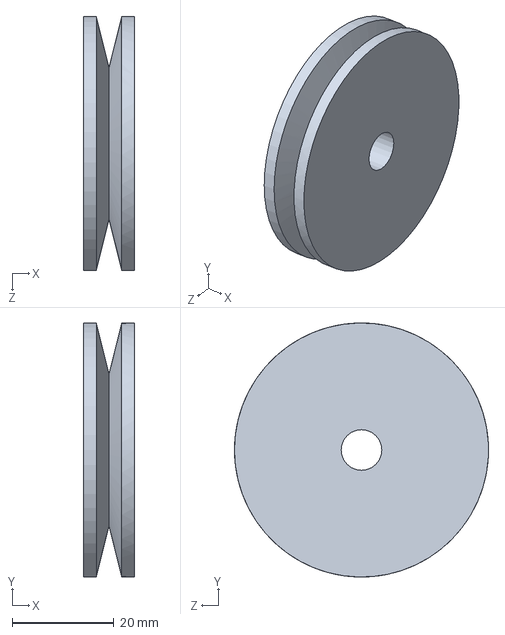
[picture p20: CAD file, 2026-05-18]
CAD-Models/Base Assembly/winding pulley.SLDPRT
10.0 x 50.0 x 50.0 mm

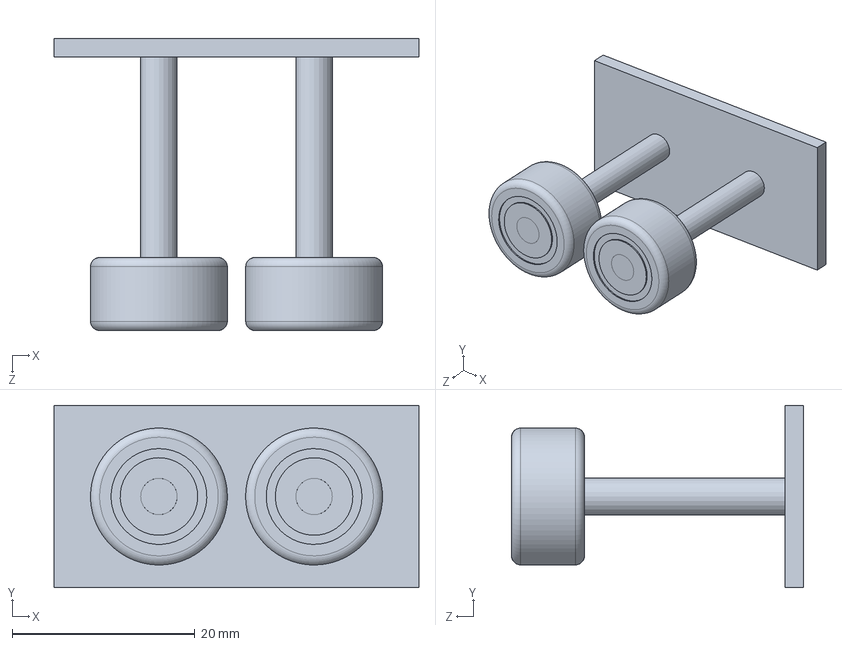
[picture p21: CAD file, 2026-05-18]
CAD-Models/Frames Assembly/Gliding roller.SLDPRT
40.0 x 20.0 x 32.0 mm

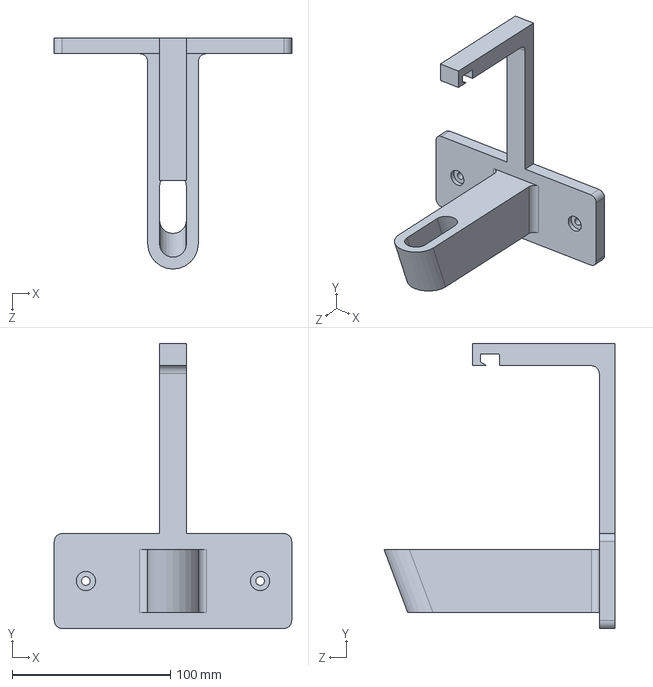
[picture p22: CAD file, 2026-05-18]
CAD-Models/Paint Plate/Mounting to be 3D printed.SLDPRT
150.0 x 180.0 x 146.0 mm

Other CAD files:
CAD-Models/Paint Plate/ultrasonic holder2.SLDPRT
CAD-Models/Base Assembly/PMDC motor.SLDPRT
CAD-Models/Frames Assembly/lim_2.SLDPRT
CAD-Models/Base Assembly/trolly wheels .SLDPRT
CAD-Models/Base Assembly/Arduino.SLDPRT
CAD-Models/Base Assembly/Square geared box motor.sldprt
CAD-Models/Base Assembly/Track.SLDPRT
CAD-Models/Base Assembly/pulley for track.SLDPRT
CAD-Models/Base Assembly/side mount.SLDPRT
CAD-Models/Frames Assembly/Lim_1.SLDPRT
CAD-Models/Frames Assembly/Lim_6.SLDPRT
CAD-Models/Frames Assembly/Pulley.SLDPRT
CAD-Models/Frames Assembly/Toggle Switch.SLDPRT

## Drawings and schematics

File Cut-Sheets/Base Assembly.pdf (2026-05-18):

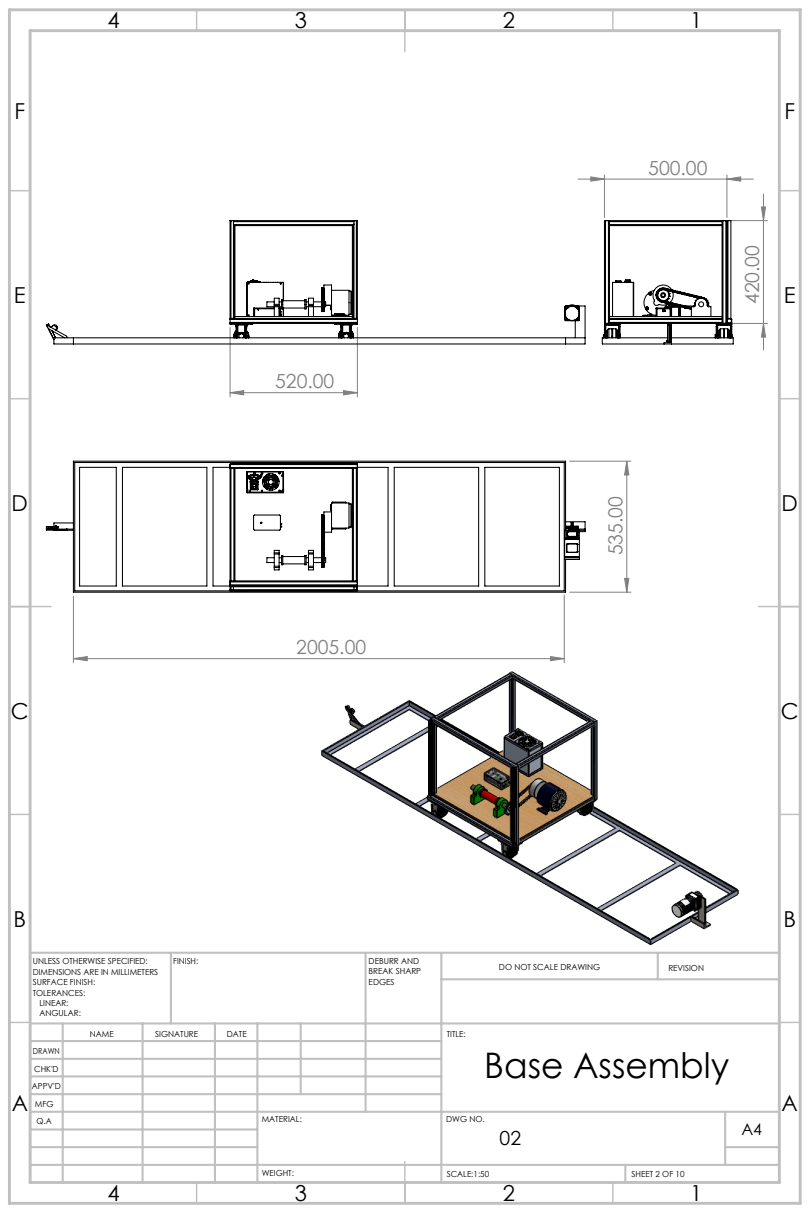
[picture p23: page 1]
FINISH:; DEBURR AND; BREAK SHARP; DO NOT SCALE DRAWING; REVISION; SCALE:1:50; SHEET 2 OF 10

UNLESS OTHERWISE SPECIFIED:
DIMENSIONS ARE IN MILLIMETERS
SURFACE FINISH:
TOLERANCES:
LINEAR:
ANGULAR:

NAME | SIGNATURE | DATE | | | | TITLE: Base Assembly

DRAWN
CHK'D
APPV'D
MFG
Q.A | | | | MATERIAL: | DWG NO. 02 | A4

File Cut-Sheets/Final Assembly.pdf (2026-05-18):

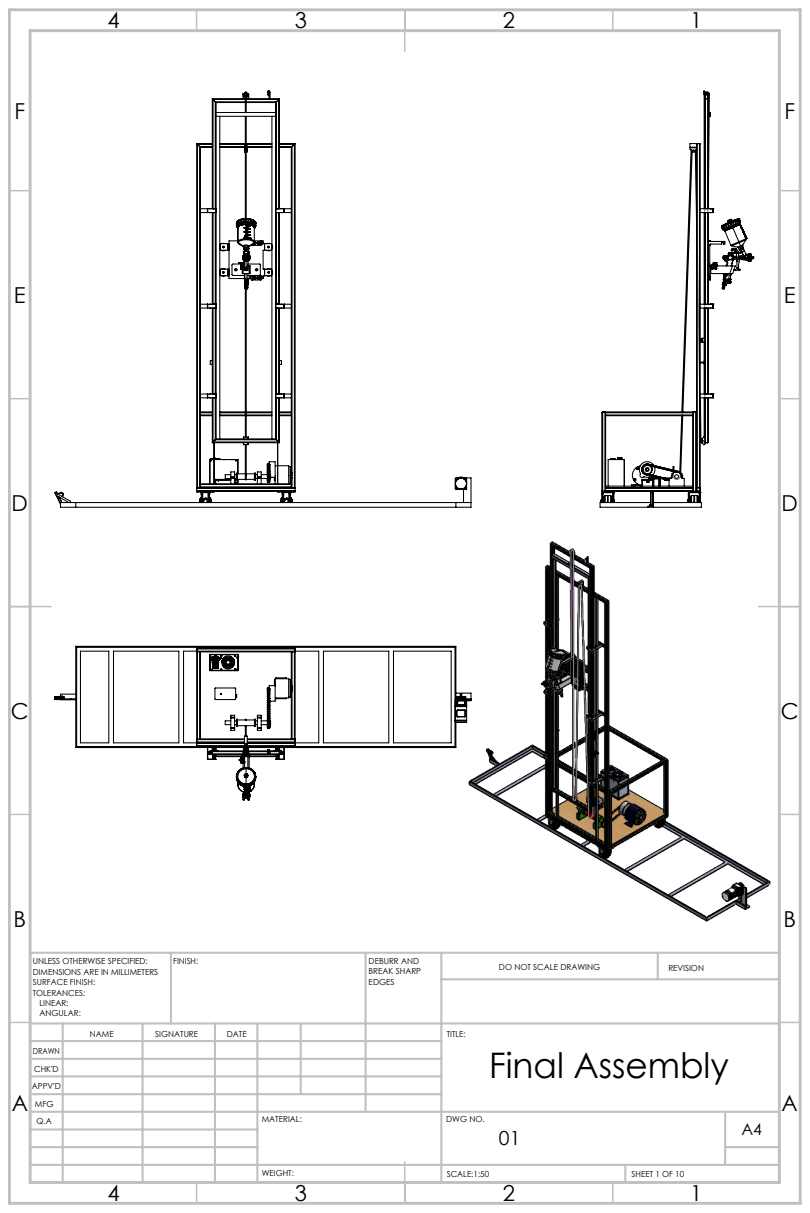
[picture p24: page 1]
FINISH:; DEBURR AND; BREAK SHARP; DO NOT SCALE DRAWING; REVISION; SCALE:1:50; SHEET 1 OF 10

UNLESS OTHERWISE SPECIFIED:
DIMENSIONS ARE IN MILLIMETERS
SURFACE FINISH:
TOLERANCES:
LINEAR:
ANGULAR:

NAME | SIGNATURE | DATE | | | | TITLE: Final Assembly

DRAWN
CHK'D
APPV'D
MFG
Q.A | | | | MATERIAL: | DWG NO. 01 | A4

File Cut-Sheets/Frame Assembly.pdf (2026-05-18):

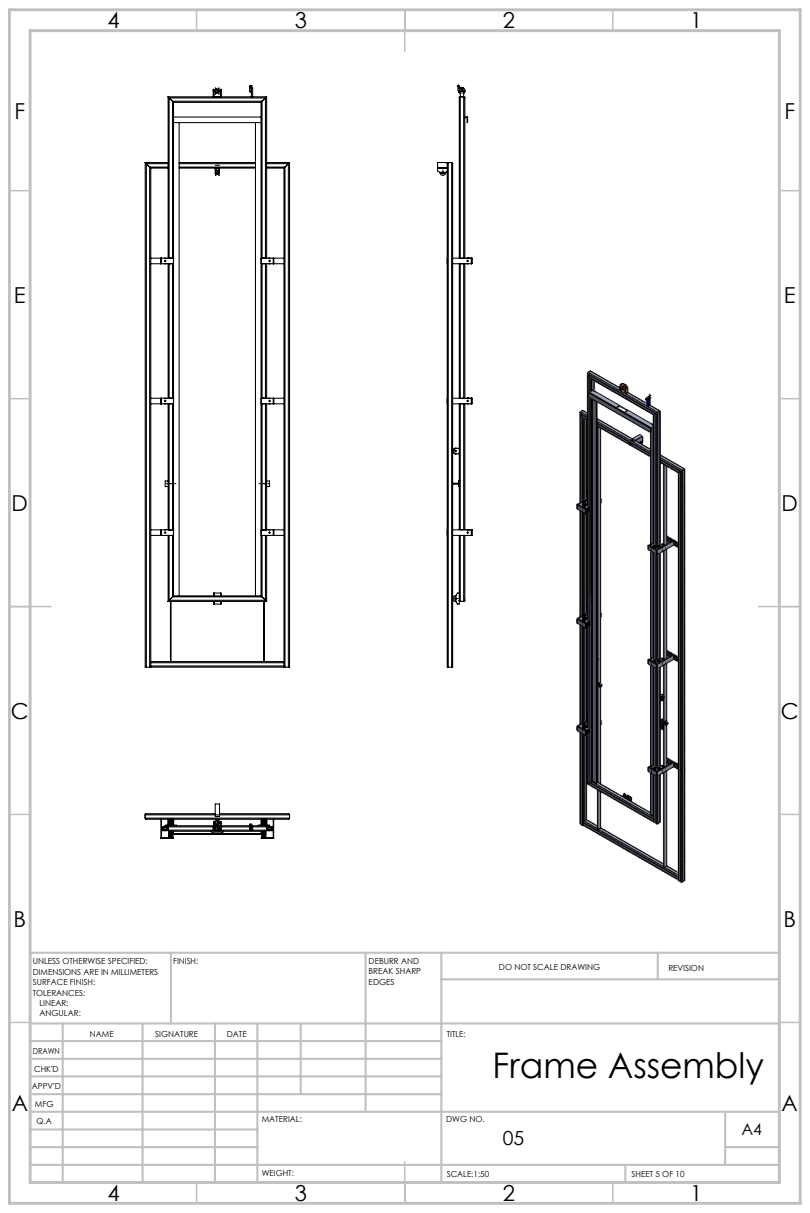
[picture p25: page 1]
FINISH:; DEBURR AND; BREAK SHARP; DO NOT SCALE DRAWING; REVISION; SCALE:1:50; SHEET 5 OF 10

UNLESS OTHERWISE SPECIFIED:
DIMENSIONS ARE IN MILLIMETERS
SURFACE FINISH:
TOLERANCES:
LINEAR:
ANGULAR:

NAME | SIGNATURE | DATE | | | | TITLE: Frame Assembly

DRAWN
CHK'D
APPV'D
MFG
Q.A | | | | MATERIAL: | DWG NO. 05 | A4

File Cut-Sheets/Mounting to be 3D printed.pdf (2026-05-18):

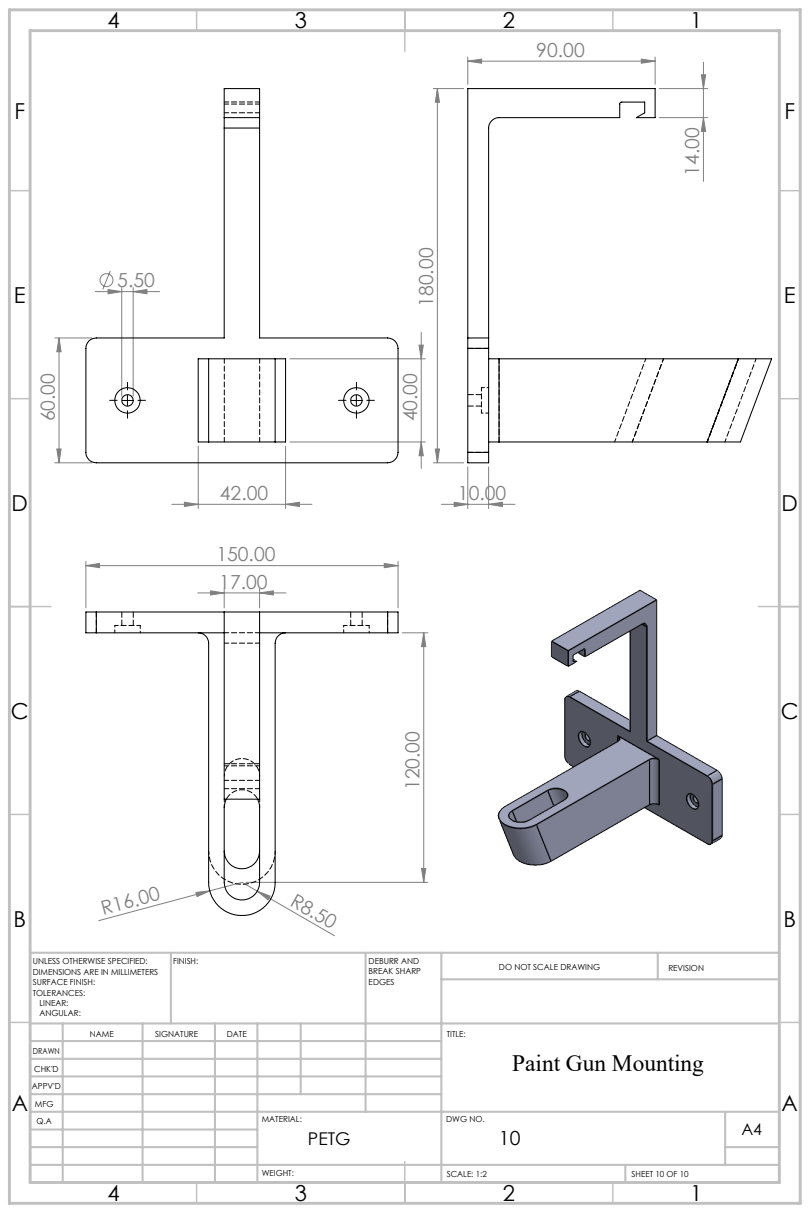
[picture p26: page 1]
FINISH:; DEBURR AND; BREAK SHARP; DO NOT SCALE DRAWING; REVISION; SCALE: 1:2; SHEET 10 OF 10

UNLESS OTHERWISE SPECIFIED:
DIMENSIONS ARE IN MILLIMETERS
SURFACE FINISH:
TOLERANCES:
LINEAR:
ANGULAR:

NAME | SIGNATURE | DATE | | | | TITLE: Paint Gun Mounting

DRAWN
CHK'D
APPV'D
MFG
Q.A | | | | MATERIAL: PETG | DWG NO. 10 | A4

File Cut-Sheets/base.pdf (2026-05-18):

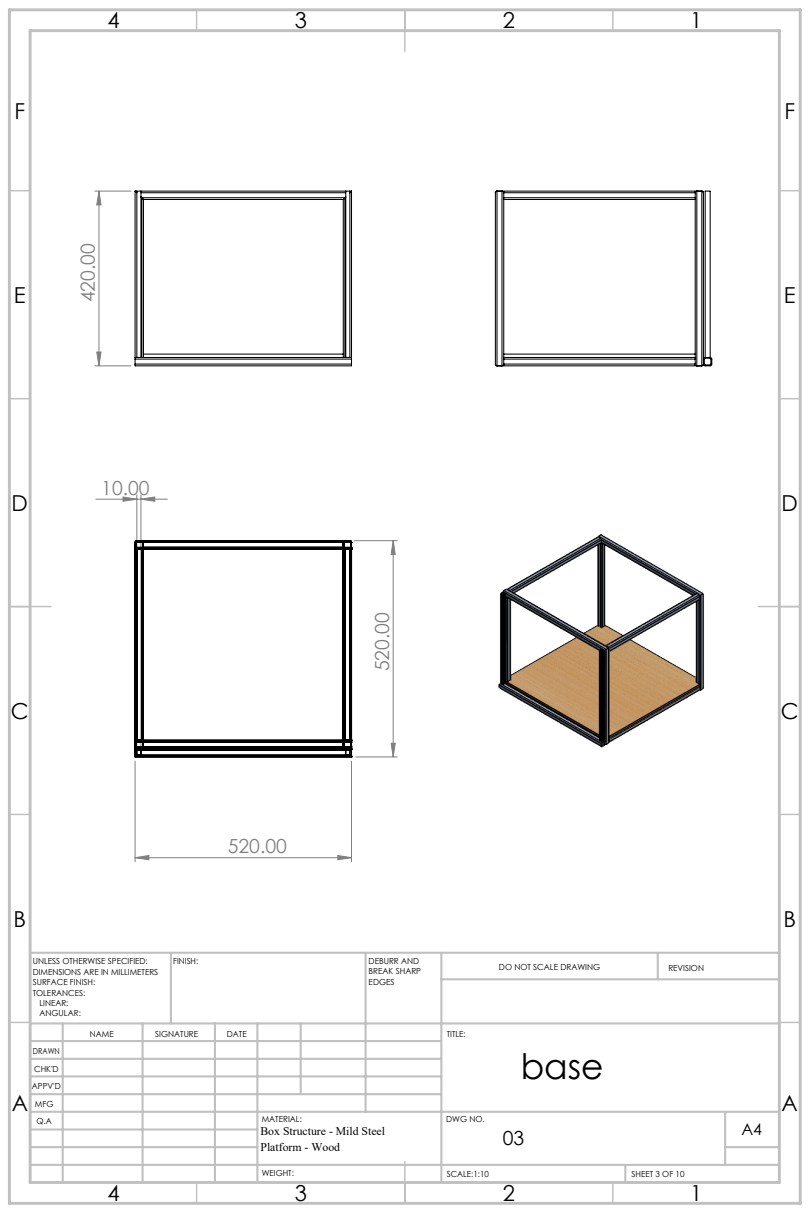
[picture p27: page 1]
FINISH:; DEBURR AND; BREAK SHARP; DO NOT SCALE DRAWING; REVISION; SCALE:1:10; SHEET 3 OF 10

UNLESS OTHERWISE SPECIFIED:
DIMENSIONS ARE IN MILLIMETERS
SURFACE FINISH:
TOLERANCES:
LINEAR:
ANGULAR:

NAME | SIGNATURE | DATE | | | | TITLE: base

DRAWN
CHK'D
APPV'D
MFG
Q.A | | | | MATERIAL: Platform - Wood | DWG NO. 03 Box Structure - Mild Steel | A4

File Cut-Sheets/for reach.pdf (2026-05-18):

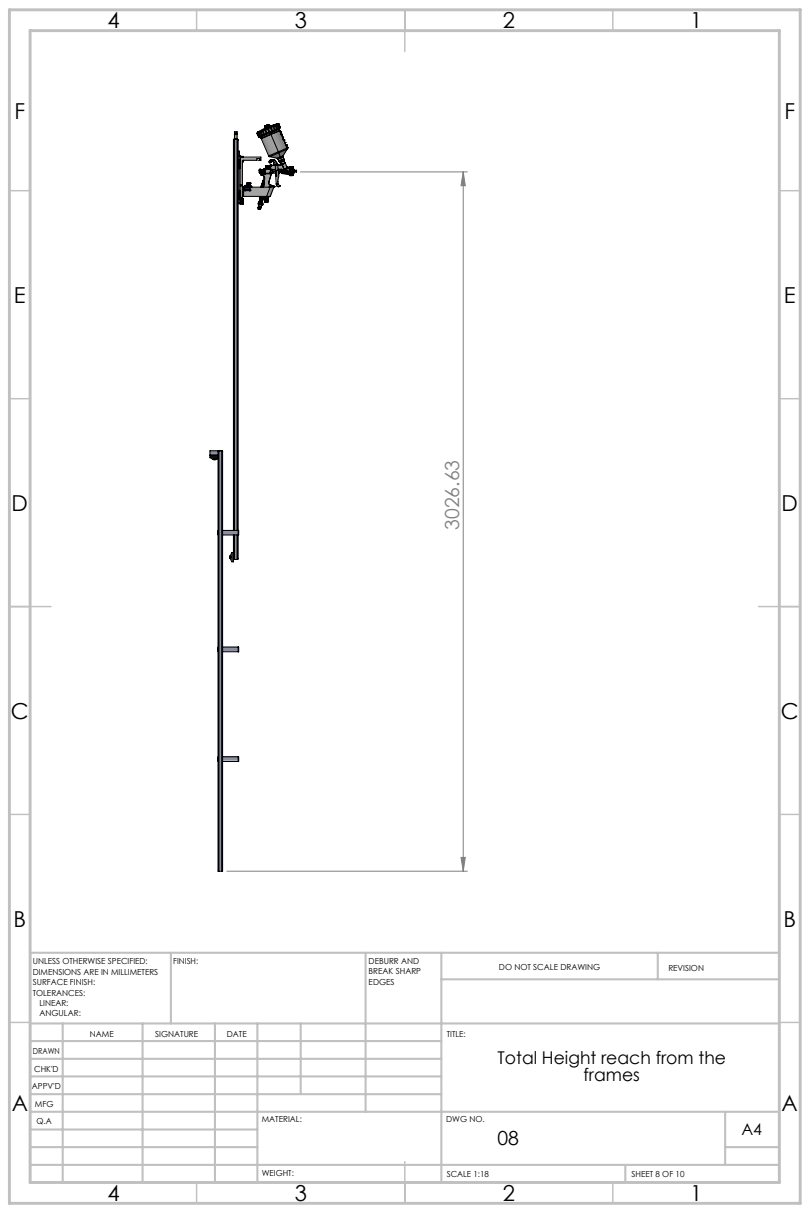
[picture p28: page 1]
FINISH:; DEBURR AND; BREAK SHARP; DO NOT SCALE DRAWING; REVISION; SCALE 1:18; SHEET 8 OF 10

UNLESS OTHERWISE SPECIFIED:
DIMENSIONS ARE IN MILLIMETERS
SURFACE FINISH:
TOLERANCES:
LINEAR:
ANGULAR:

NAME | SIGNATURE | DATE | | | | TITLE: Total Height reach from the frames

DRAWN
CHK'D
APPV'D
MFG
Q.A | | | | MATERIAL: | DWG NO. 08 | A4

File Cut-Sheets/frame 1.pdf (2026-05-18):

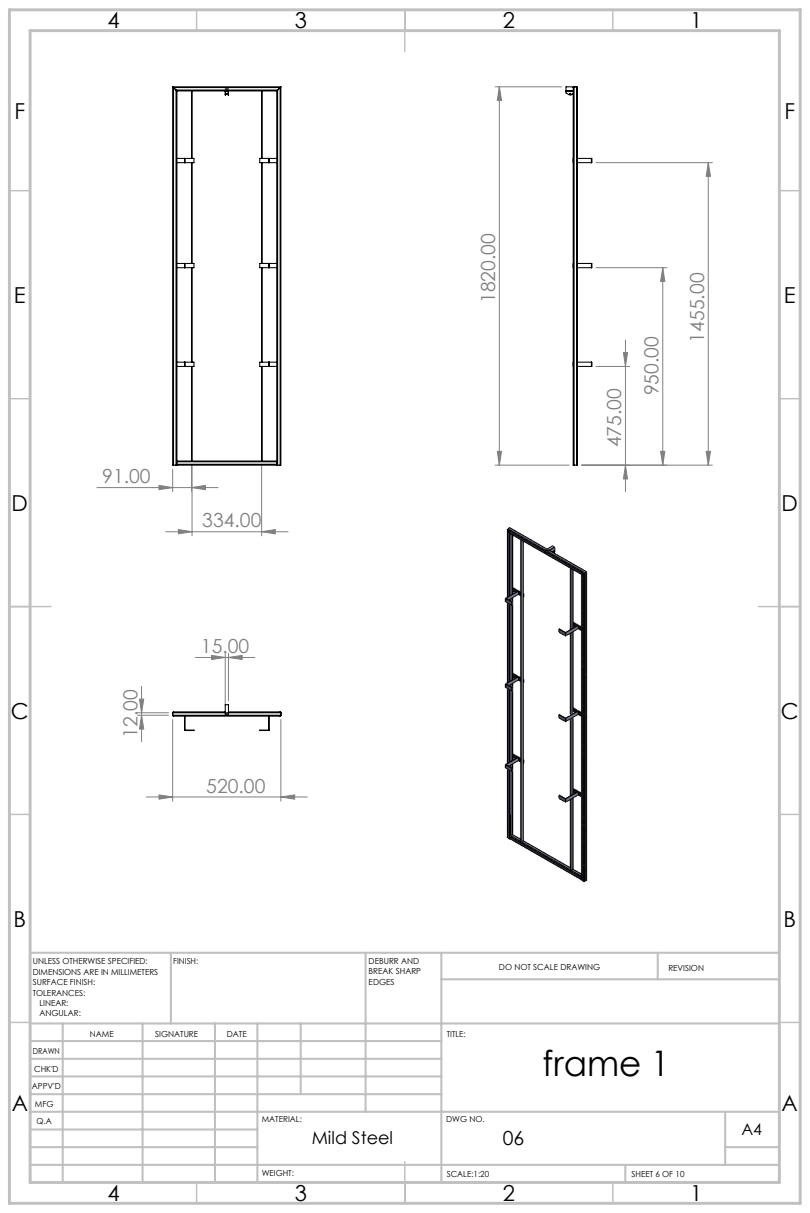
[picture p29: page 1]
FINISH:; DEBURR AND; BREAK SHARP; DO NOT SCALE DRAWING; REVISION; SCALE:1:20; SHEET 6 OF 10

UNLESS OTHERWISE SPECIFIED:
DIMENSIONS ARE IN MILLIMETERS
SURFACE FINISH:
TOLERANCES:
LINEAR:
ANGULAR:

NAME | SIGNATURE | DATE | | | | TITLE: frame 1

DRAWN
CHK'D
APPV'D
MFG
Q.A | | | | MATERIAL: Mild Steel | DWG NO. 06 | A4

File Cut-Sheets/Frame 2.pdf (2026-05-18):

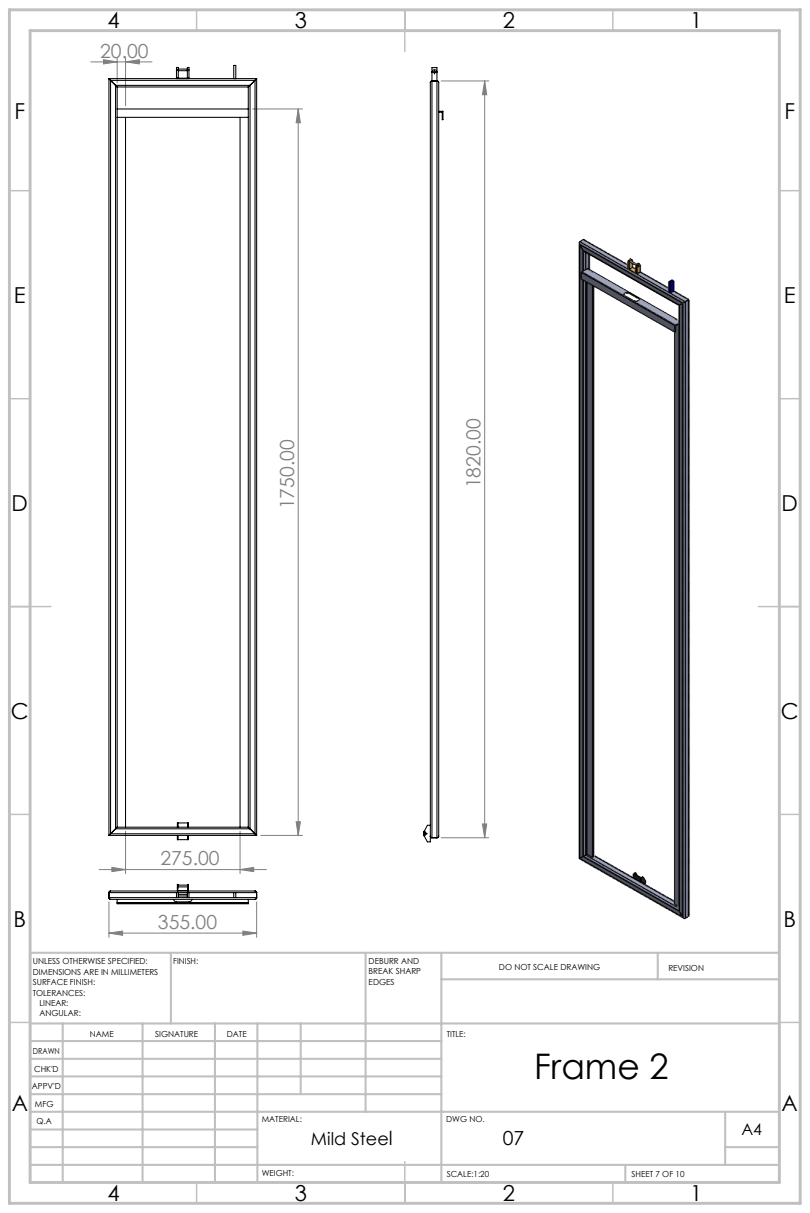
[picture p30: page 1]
FINISH:; DEBURR AND; BREAK SHARP; DO NOT SCALE DRAWING; REVISION; SCALE:1:20; SHEET 7 OF 10

UNLESS OTHERWISE SPECIFIED:
DIMENSIONS ARE IN MILLIMETERS
SURFACE FINISH:
TOLERANCES:
LINEAR:
ANGULAR:

NAME | SIGNATURE | DATE | | | | TITLE: Frame 2

DRAWN
CHK'D
APPV'D
MFG
Q.A | | | | MATERIAL: Mild Steel | DWG NO. 07 | A4

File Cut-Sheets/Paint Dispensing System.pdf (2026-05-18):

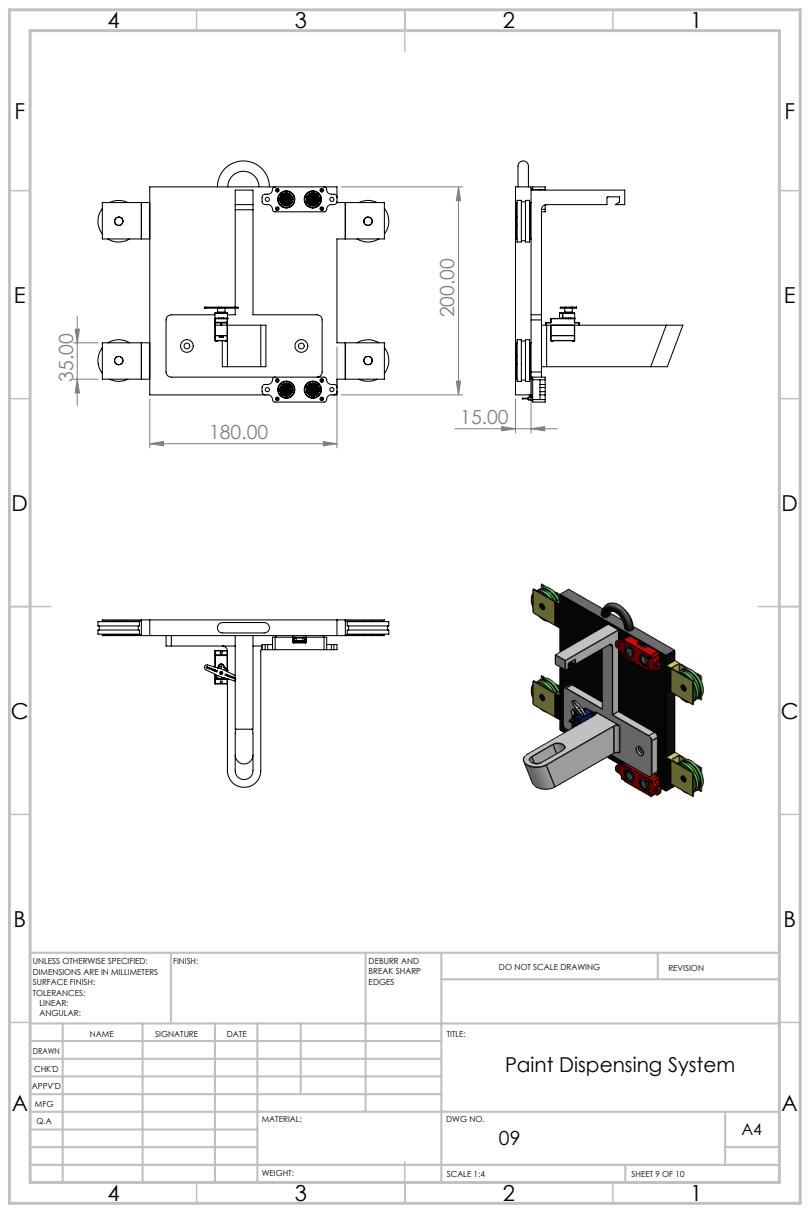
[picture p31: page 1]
FINISH:; DEBURR AND; BREAK SHARP; DO NOT SCALE DRAWING; REVISION; SCALE 1:4; SHEET 9 OF 10

UNLESS OTHERWISE SPECIFIED:
DIMENSIONS ARE IN MILLIMETERS
SURFACE FINISH:
TOLERANCES:
LINEAR:
ANGULAR:

NAME | SIGNATURE | DATE | | | | TITLE: Paint Dispensing System

DRAWN
CHK'D
APPV'D
MFG
Q.A | | | | MATERIAL: | DWG NO. 09 | A4

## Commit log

2026-05-18 Create CAD
2026-05-18 Create BOM
2026-05-18 Rename Screenshot 2023-07-11 180519-PhotoRoom.png-PhotoRoom.png to Final Prototype Pic.png
